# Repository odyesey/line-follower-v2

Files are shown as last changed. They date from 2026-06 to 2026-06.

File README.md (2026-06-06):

# Line follower v2

## About

As the name suggests, its the second version with custom pcb and better hardware. I use PCB as a chasis and mount all components on it. For wheels, I designed mold in CAD to make silicone tires. Tire diameter is less than wheel diameter, so it sticks better and lowers the chance of slipping off

## Features

- Detect and avoid obstacles
- PID control
- OLED Display to show values
- Buttons to tune PID values
- Buzzer to signal start
- Low voltage alarm

## How to open PCB files
- Go to EasyEDA Std
- Go to File > Open > EasyEDA
- Select easyeda.zip file in PCB folder
- Click Import

## Images

### CAD View
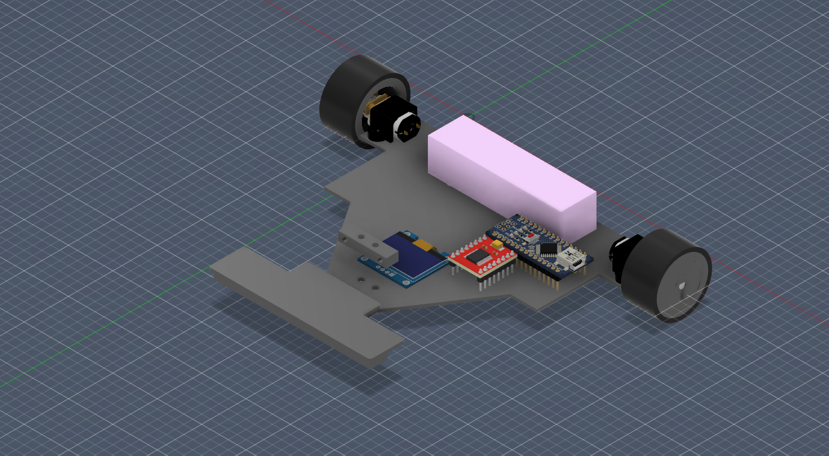
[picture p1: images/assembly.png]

**Note:** I couldn't find CAD models of some components, so I matched mount holes instead. All dimensions are correct

### 3D View
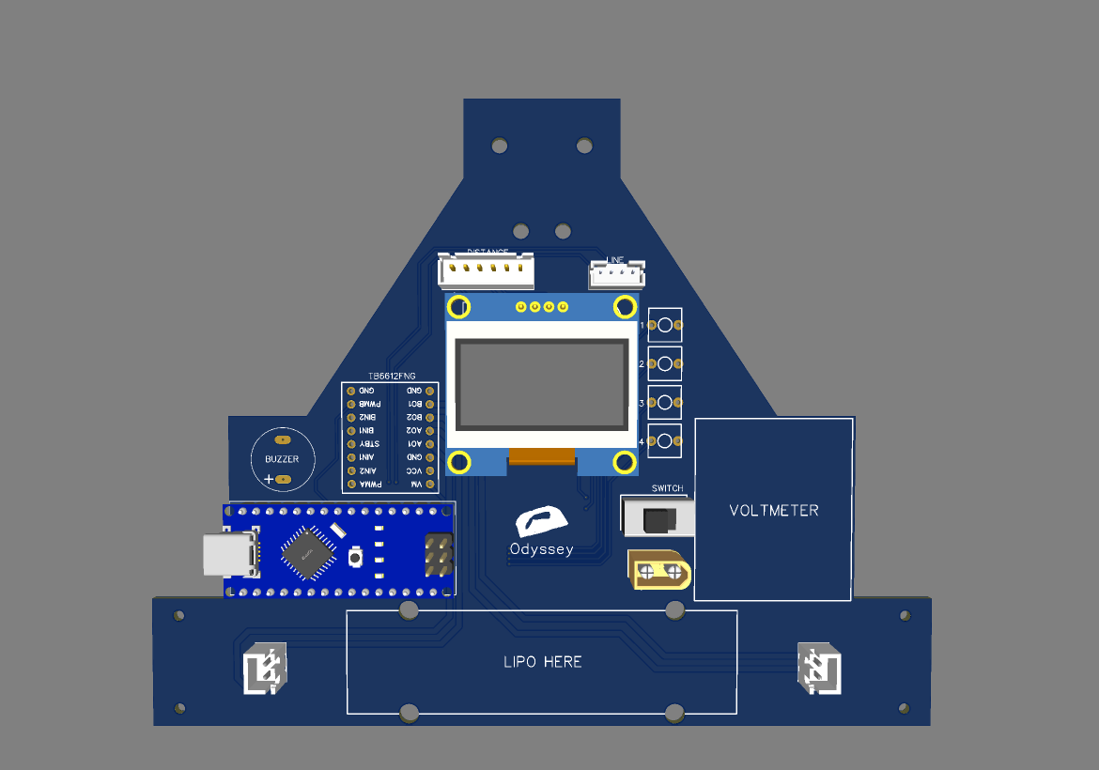
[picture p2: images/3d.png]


### 2D View
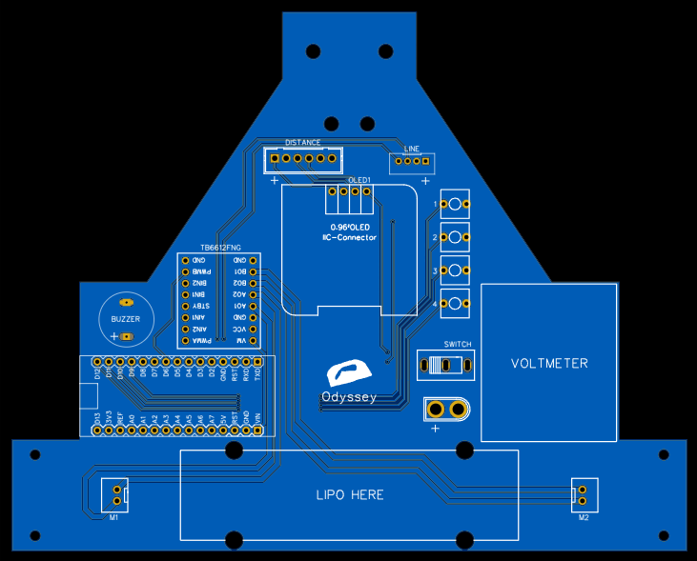
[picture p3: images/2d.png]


### Schematic
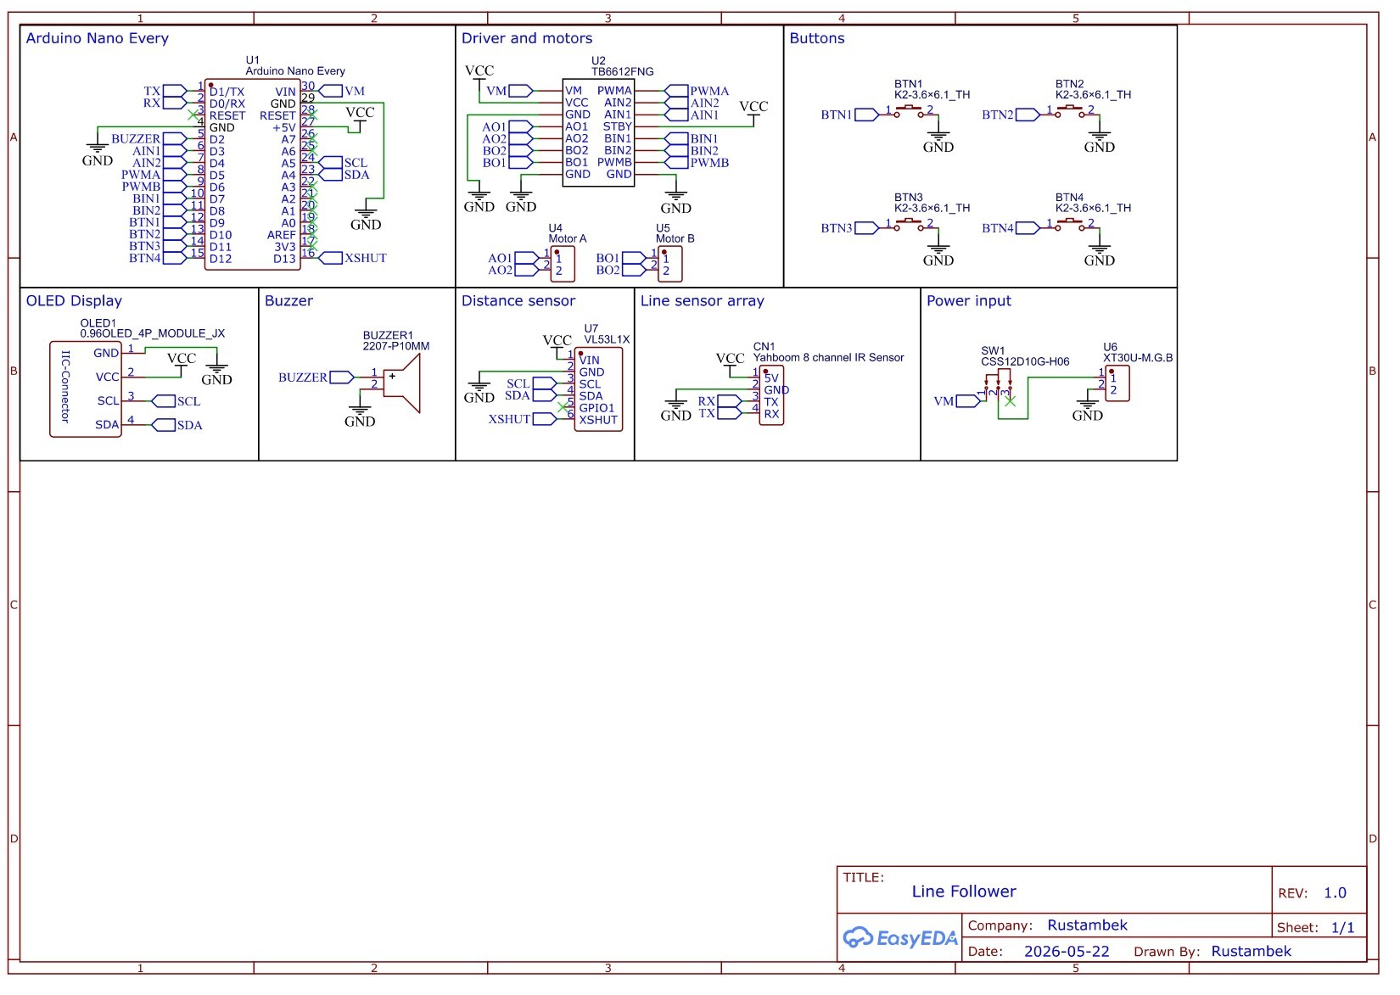
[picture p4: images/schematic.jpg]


### CAD

| Assembly | Mold |
| --- | --- |
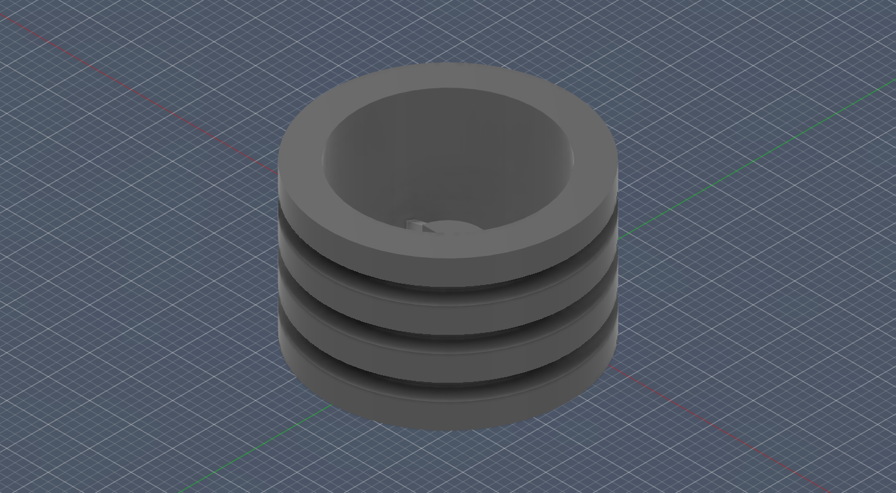
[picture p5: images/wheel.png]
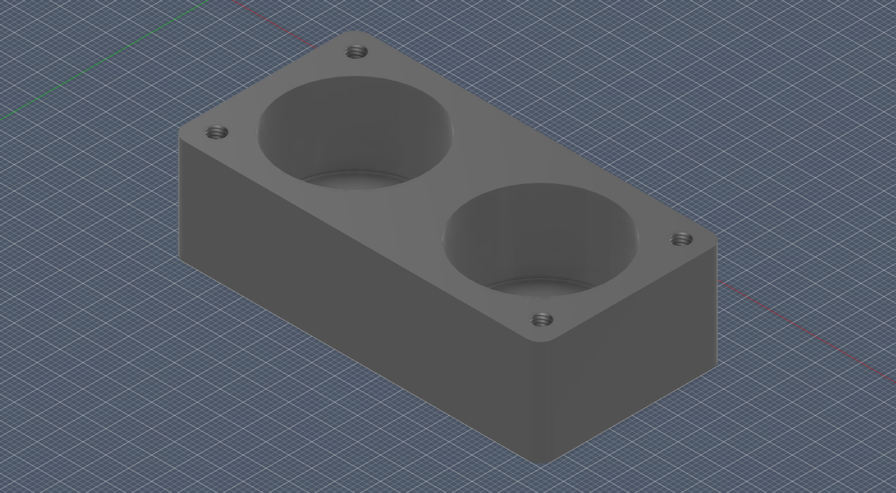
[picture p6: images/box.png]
|  box.stl |  box.stl |
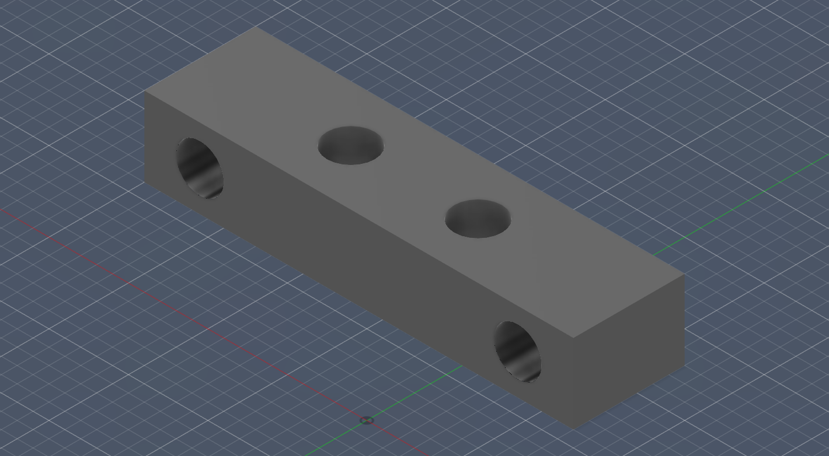
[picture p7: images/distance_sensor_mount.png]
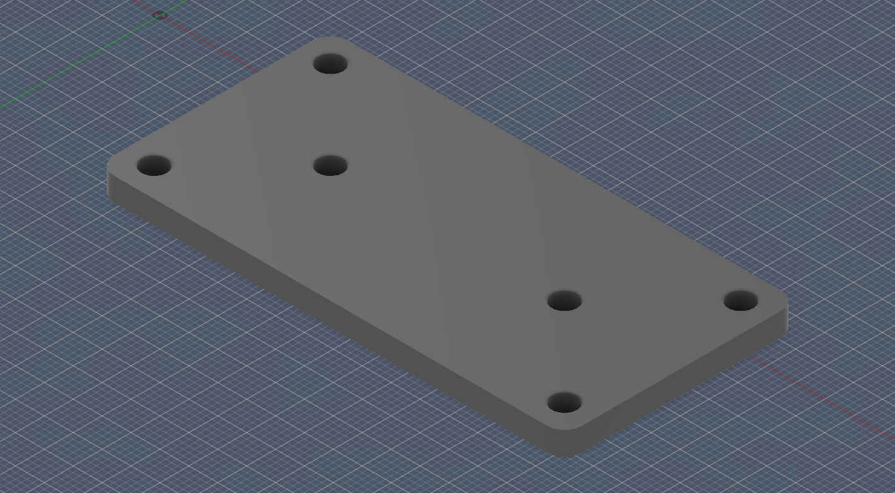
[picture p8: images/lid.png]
|  distance_sensor_mount.stl |  lid.stl|
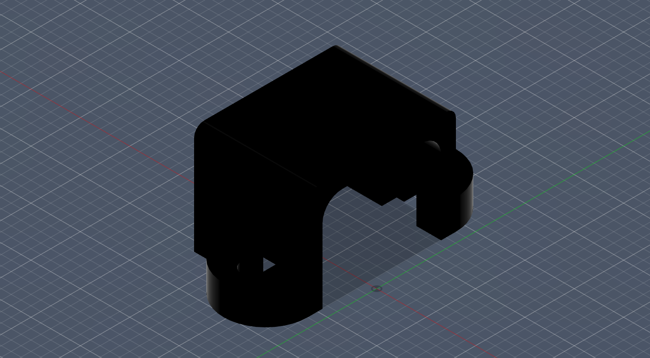
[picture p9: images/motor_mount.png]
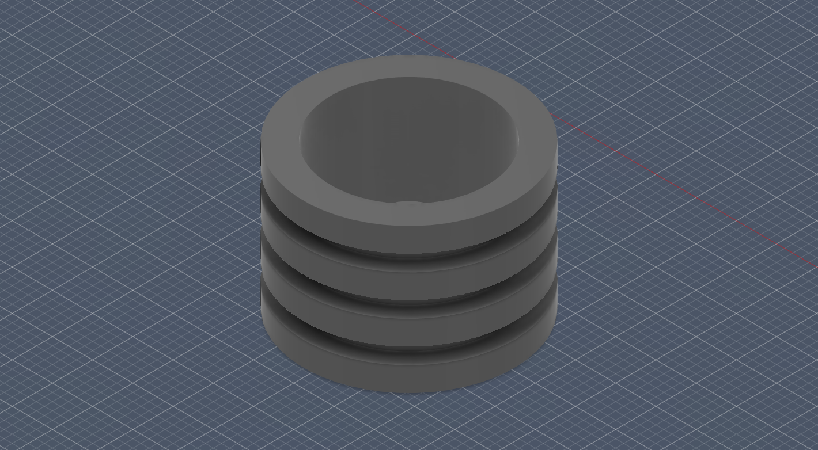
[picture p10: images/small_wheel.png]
|  motor_mount.stl |  small_wheel.stl |

**Note:** motor_mount.stl isn't mine, so uploaded copyright

## Gerbers
Gerbers file is in Fabrication folder, I chose black as a PCB color

## 3D Print (jlc3dp.com)

|File |Quantity|Material |
|---|---|---|
|box.stl |1 |JLC Black Resin|
|lid.stl |1 |JLC Black Resin|
|small_wheel.stl |2 |JLC Black Resin|
|wheel.stl |2 |PA12-HP Nylon  |
|motor_mount.stl |2 |PA12-HP Nylon  |
|distance_sensor_mount.stl|1 |PA12-HP Nylon  |

## BOM

|Name |Quantity|Total Cost (USD)|Link |
|---|---|---|---|
|N20 motor 12V 500RPM |2 |4.2 |https://ali.click/gukjd1s|
|IMAX B6 Balance charger |1 |28.48 |https://ali.click/nadmd1u|
|VL53L1X |1 |3.04 |https://ali.click/zucjd1w|
|JST PH2.0 4P connector |1 |0.78 |https://ali.click/thyid1k|
|JST XH2.54 6P wire + connector |1 |1.06 |https://ali.click/dawid1q|
|JST XH2.54 2P wire + connector |2 |0.54 |https://ali.click/jwvid1j|
|M2 screw |4 |1.76 |https://ali.click/vkvid1w|
|M2 nut |4 |0.48 |https://ali.click/bfvid1k|
|Releasable zip ties |1 |1.81 |https://ali.click/wctid1n|
|XT30U-M Connector |1 |0.88 |https://ali.click/g5tid1h|
|Switch |1 |0.98 |https://ali.click/rosid1l|
|Lipo 3s 72mm x 18mm |2 |20 |https://ali.click/qedmd18|
|Female pin header 1x15 |2 |1.26 |https://ali.click/tmyfd1y|
|Short male pin header 1x4 |1 |0.87 |https://ali.click/xeyfd1s|
|OLED Display 128x64 4P |1 |1.59 |https://ali.click/hayfd1t|
|TMB12A05 |1 |2 |https://ali.click/k2yfd11|
|Female pin header 1x8 |2 |0.73 |https://ali.click/qnxfd1k|
|2 pin button |4 |1 |https://ali.click/rzwfd1p|
|Lipo Voltmeter |1 |1.2 |https://ali.click/grcjd17|
|Arduino Nano Every |1 |16.2 |https://ali.click/9npcd1e|
|Yahboom 8 channel IR sensor (Full pack)|1 |11.95 |https://ali.click/u2svc1b|
|TB6612FNG |1 |0.86 |https://ali.click/hkdmd1x|
|M3 nut |2 |0.87 |https://ali.click/kqdmd1u|
|M4 screw length>=35mm |6 |1.68 |https://ali.click/0memd11|
|M4 nut |6 |0.73 |https://ali.click/rgemd1v|

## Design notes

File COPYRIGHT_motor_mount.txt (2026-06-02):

MODEL: https://grabcad.com/library/motor-mount-for-ga12-n20-1
AUTHOR: https://grabcad.com/tu.n.quang-6

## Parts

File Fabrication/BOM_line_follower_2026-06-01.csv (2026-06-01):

ID | Name | Designator | Footprint | Quantity | Manufacturer Part | Manufacturer | Supplier | Supplier Part | Price
1 | K2-3.6×6.1_TH | 1,2,3,4 | KEY-TH_2P | 4 | K2-1107ST-A4SW-06 |  | LCSC | C118141 | 0.074
2 | 2207-P10MM | BUZZER | BUZZER_BEEPER:BUZZER_12X9.5RM7.6 | 1 | 2207-P10MM | XHXDZ(兴华鑫) | LCSC | C49246969 | 0.153
3 | Yahboom 8 channel IR Sensor | LINE | CONN-TH_PH2.0-4P | 1 | PH2.0-4P | CAX(创都) | LCSC | C722763 | 0.014
4 | 0.96OLED_4P_MODULE_JX | OLED1 | 0.96OLED_4P | 1 | 0.96OLED_4P_MODULE_JX | null | LCSC | C9900004566
5 | CSS12D10G-H06 | SWITCH | SW-TH_3P-P4.80-HX-SS12D10G4 | 1 | CSS12D10G-H06 | JXTCONN(聚兴泰) | LCSC | C49435501 | 0.264
6 | Arduino Nano Every | U1 | COMM-TH_ARDUINO_NANO | 1 | ARDUINO_NANO | null | LCSC | C9900017879
7 | TB6612FNG | TB6612FNG | TB6612-BOARD | 1
8 | Motor A | M1 | CONN-TH_2P-P2.50-XH2.54-2P | 1 | XH-2P-2.54 | null | LCSC | C9900003929
9 | Motor B | M2 | CONN-TH_2P-P2.50-XH2.54-2P | 1 | XH-2P-2.54 | null | LCSC | C9900003929
10 | XT30U-M.G.B | U6 | CONN-TH_XT30U-M | 1 | XT30U-M.G.B | AMASS(艾迈斯) | LCSC | C19268020
11 | VL53L1X | DISTANCE | CONN-TH_B6B-XH-A-GU | 1 | B6B-XH-A-GU | JST | LCSC | C265366 | 2.362

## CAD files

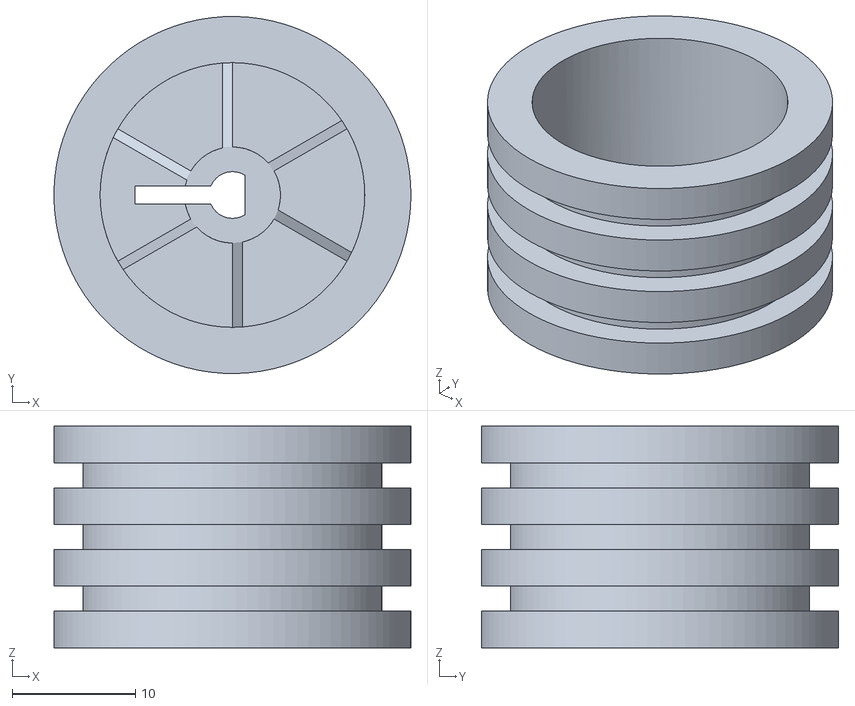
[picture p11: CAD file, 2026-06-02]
CAD/wheel.stl
29.0 x 29.0 x 18.0

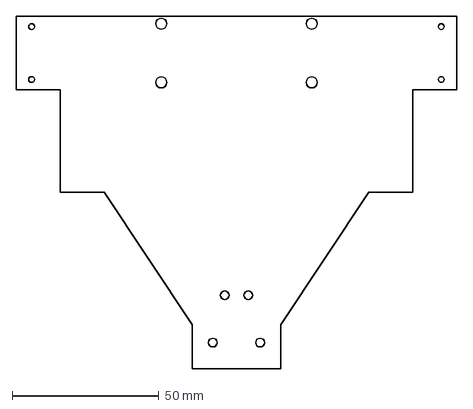
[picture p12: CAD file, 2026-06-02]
PCB/BoardOutline.dxf
150.0 x 120.0 mm

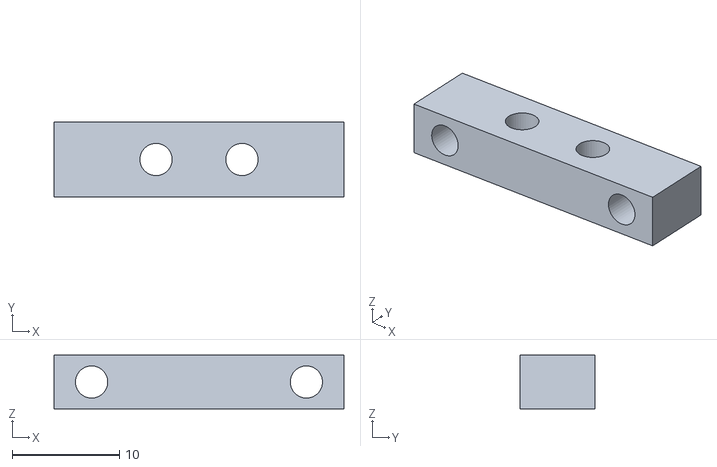
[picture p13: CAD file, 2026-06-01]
CAD/distance_sensor_mount.stl
27.0 x 7.00 x 5.00

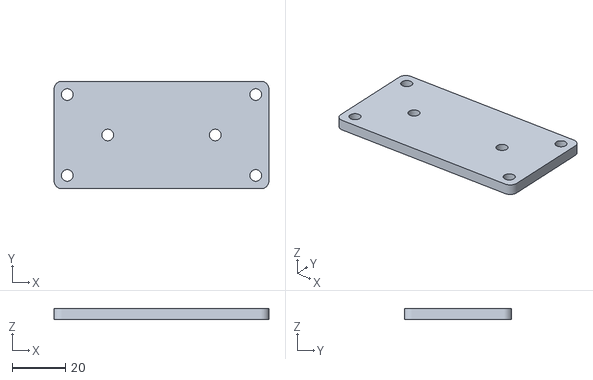
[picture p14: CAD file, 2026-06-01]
CAD/lid.stl
81.0 x 40.5 x 4.00

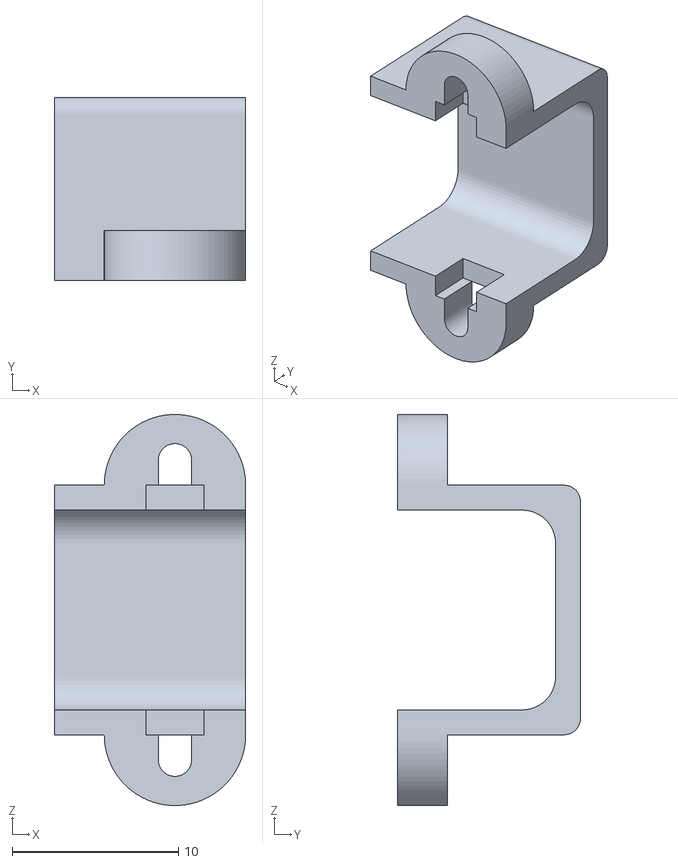
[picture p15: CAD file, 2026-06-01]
CAD/motor_mount.stl
11.5 x 11.0 x 23.5

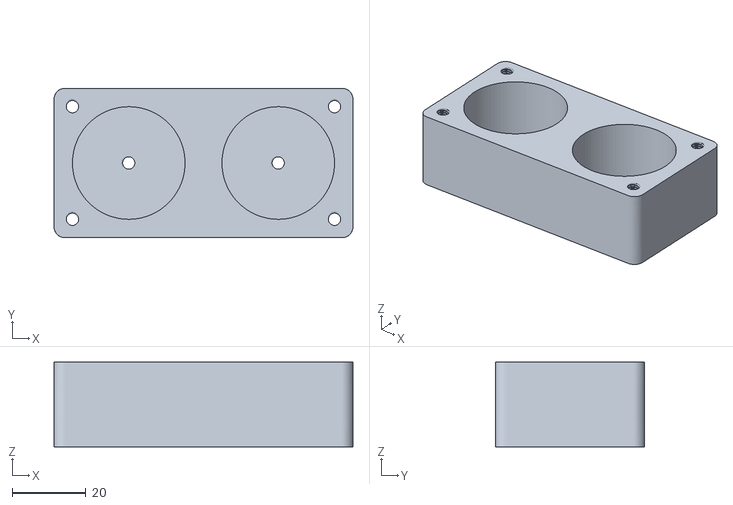
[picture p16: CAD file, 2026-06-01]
CAD/box.stl
81.0 x 40.5 x 23.0

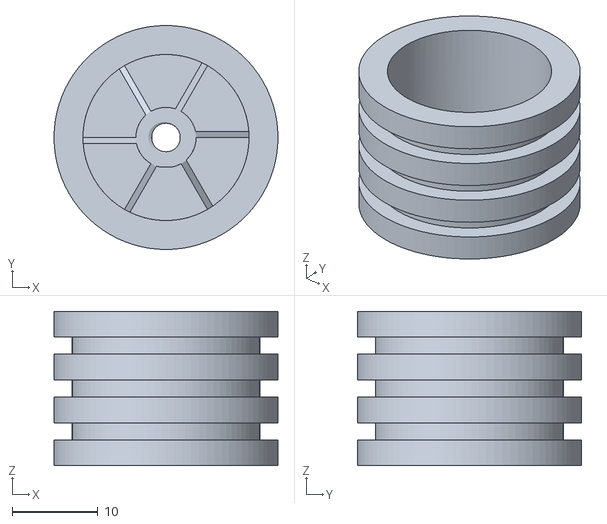
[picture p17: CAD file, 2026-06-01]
CAD/small_wheel.stl
26.1 x 26.1 x 18.0

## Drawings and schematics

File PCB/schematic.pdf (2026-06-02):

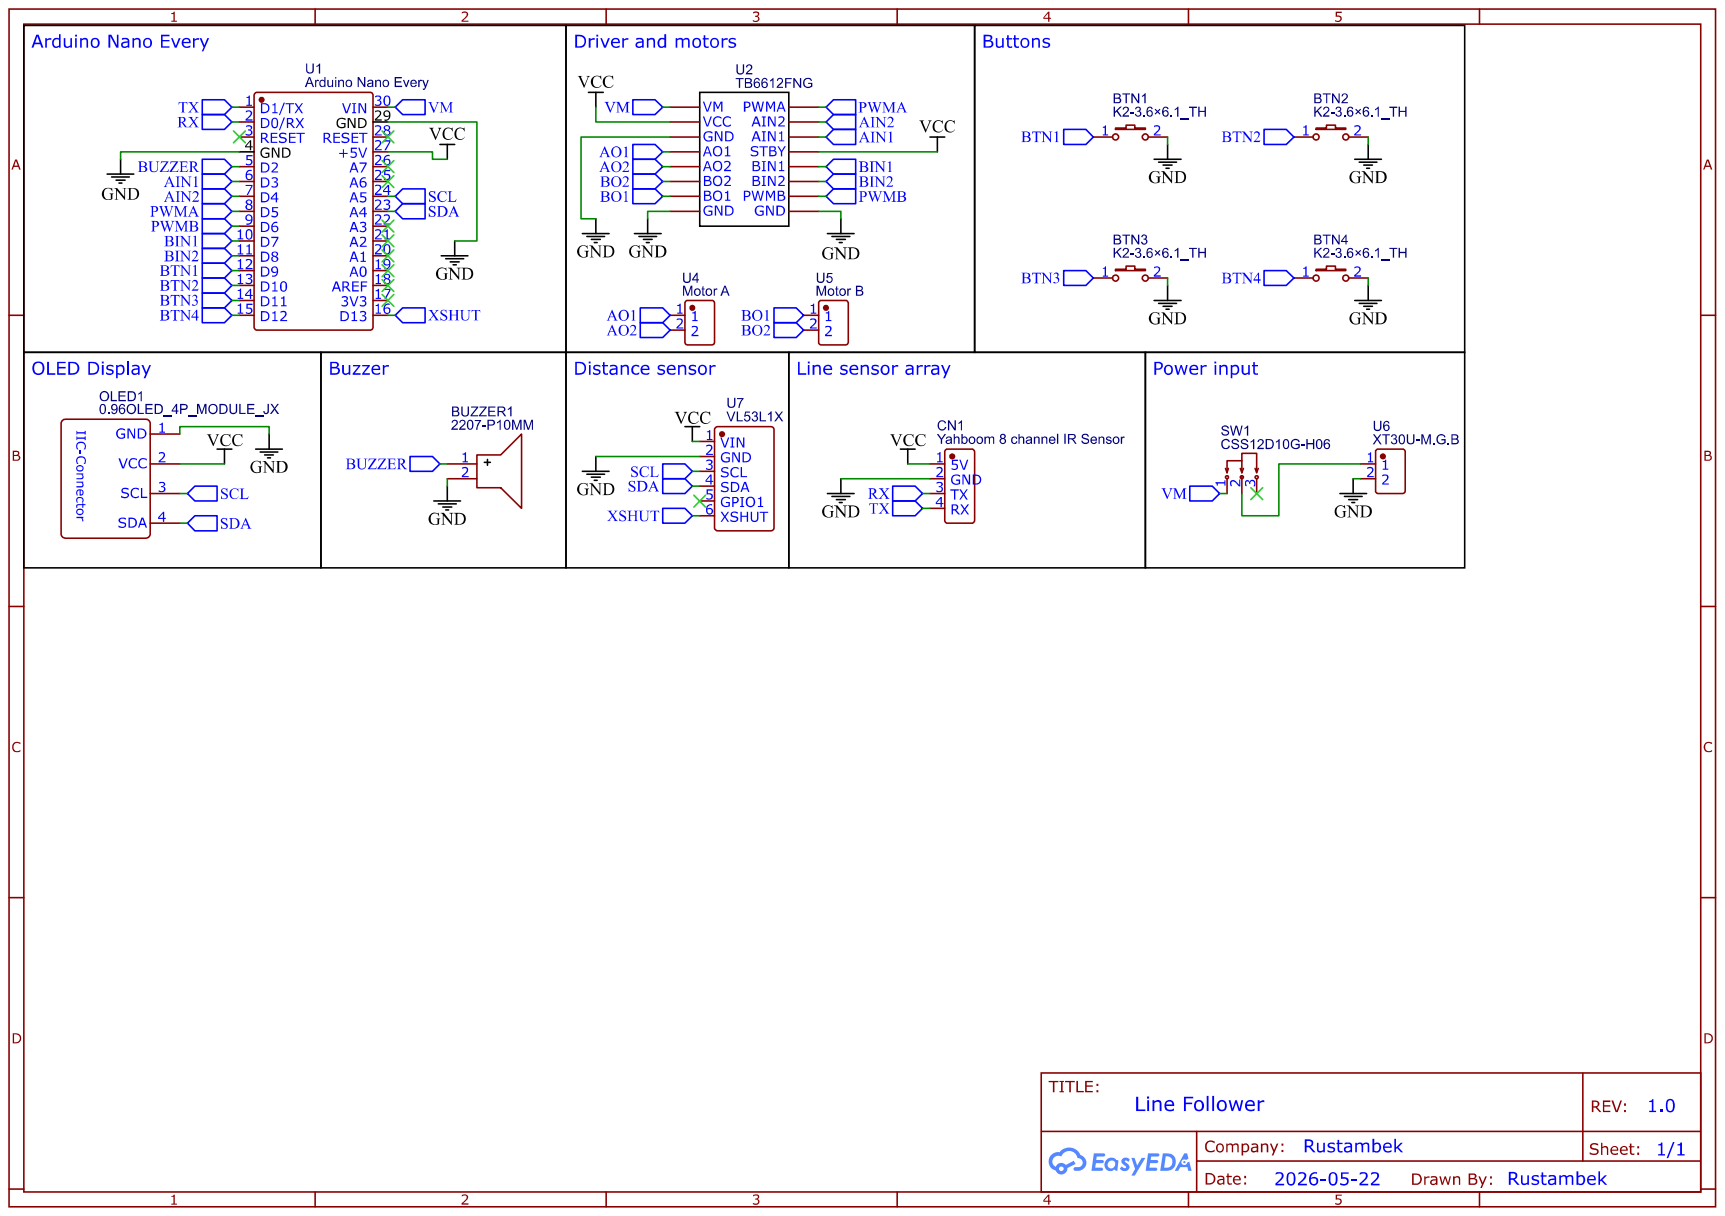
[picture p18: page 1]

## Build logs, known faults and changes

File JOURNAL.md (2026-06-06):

<!--
  This journal is auto generated by Stasis.
-->

# 6/2/2026 5 PM - Removed gyroscope, some components and updated wheel model

_Time spent: 0.25h_

schematic


Gyroscope adds extra money to the budget, and I think leaning on line sensor array is enough (8 IR sensors). I previously used LEGO EV3 gyro sensor and making exact turns was slow. If you increase speed it can overshoot. Maybe code wasn't well written. Anyway, I removed gyroscope, I don't need precise turns, robot itself will adjust its position by sensor feedback

I removed additional components of buzzer, like transistor. Because I found out, it can work directly from  digital pin

I forgot to extrude tiny face, and fixed it

Before:

After:







# 5/31/2026 8 PM - Finished pcb routing

_Time spent: 5h_



Made this in CAD to mount distance sensor. Its designed like that: you put copper columns (which comes in yahboom IR sensor array pack) on pcb and on top of that this CAD model, and mount distance sensor to the farthest holes and tighten this construction by insterting screws into copper columns (and closing them with nuts in holes without columns)



Added copper area to both layers (to GND net). I had DRC showing one unrouted GND, but I was sure all grounds are connected to each other. Even after adding copper area, this error didn't disappear. I deleted and added copper area multiple times because I messed up something (I forgot what exactly), and somehow that error disappeared



Drew a rectangle to specify a space for lipo voltmeter. It's a crucial thing because I heard if lipo battery is used at low voltage, it can burn. Voltmeter helps to monitor current voltage and beep if the battery is low, and minimum voltage to beep can be configured

The pcb's color will be black, because it looks really good. At first, I thought the blue pcb is the best option because I have colorful components (black, blue, red, green, purple). But my logo on black pcb looks better, and I think other components will blend in with this color



Made some changes for board outline: increased the space because not all components are fitting and added four holes around the battery space for zip ties (zip ties should be releaseable because I want to use 2 lipo batteries: use one while other is charging) to tighten the battery






# 5/30/2026 6 PM - Worked on pcb chasis design and placed components to check whether they fit

_Time spent: 0.75h_



Sketched this outline and drawed some circles for motor mounts and line sensor array. I should add more circles for distance sensor. Removed other lines because when importing it as a dxf, EasyEDA uses these lines as a border and cuts them into multiple PCBs. Later I found out, I could just simply remove these lines in pcb editor man



In importing dxf, you can check option that uses circles as a mount hole in EasyEDA. So convenient!

After importing board outline, it looked small, and started to worry that all components may not fit inside. But after placing tightly, they all fit inside



This isn't the final version. I should add some mount holes for a distance sensor





# 5/29/2026 1 PM - Completed the schematic

_Time spent: 1h_



Finally, finished it. That was a long run not gonna lie

I added switch and four buttons (they can be used to tune PID values without uploading a new code and start a robot with one click because line sensor array needs to be initalized first and this doesn't happen instanly, so it doesn't makes sense to run robot right after turning on)

XSHUT pin of distance sensor is now connected to digital pin



For the buzzer part, AI suggested me this diagram, and I tested it in tinkercad. I thought boom (on image) indicates arduino started working. When I pulled up another arduino with led, it worked without booms. I started to worry, maybe in real life this can burn transistor. But the reason was piezo drawing too much current. The buzzer I found draws less than 30mA of current, which is quite low to cause heating, so we are good




# 5/29/2026 9 AM - Almost finished schematic

_Time spent: 2h_



I did a lot of research not only with AI, but searched for sources on the internet. Looked for wirings and clarified things like sensor operating voltage. I'm using Yahboom's IR sensor array, so I contacted them via email to make sure I can connect to sensor with pcb

In schematic, I didn't include voltmeter for lipo battery because there is no need to do that. It automatically makes a sound when voltage is low, and minimum voltage can be configured, you just connect it to lipo. The only thing is to allocate space in pcb

This schematic at this point, is complete, except XSHUT pin in distance sensor

There a few things left: switch for turning on/off, buzzer to indicate robot started following line, and a few buttons just in case. Maybe I'll add more components



# 5/27/2026 3 PM - Uploaded models for JLC3DP

_Time spent: 0.75h_



At first, I just exported models apart and uploaded to website. I thought everthing is going to be fine, but I encountered printing risk on box.stl (in screenshot), used AI to figure out the problem, tried extruding bottom part and that worked! Used AI again, to determine which 3d printing technology to use and chose MJF (Nylon)

Honestly, I didn't expect printing price would be that much



# 5/27/2026 12 PM - Designed mold for making silicone tires

_Time spent: 0.75h_



I scaled x and y axis of the wheel from 1.0 to 0.9, so tire width remains unchanged. This makes silicone's diameter smaller than actual wheel's diamteter. That means silicone tire will stick stronger to wheels

I carved holes and made thread from them for M4 bolts, and I set tires outer thickness to 2.2mm

Used this tutorial: https://www.youtube.com/watch?v=wSwuph2TElI



# 5/25/2026 4 PM - Finished the wheel

_Time spent: 1.333333333333333h_





Changed the smooth sank middle to 3-channel design. This reduces the chances of slipping of. Also I changed support beams to triangular shape, and made wheel 2 times wider

I increased the "tip" of the wheel (where motor shaft goes) to 1mm, so widened wheel won't cover the motor that much




# 5/24/2026 4 PM - Designed wheel

_Time spent: 1h_





I designed wheels for n20 motors. Used [this](https://grabcad.com/library/wheel-43mm-for-ga12-n20-1) cad model as a reference to match the dimensions

It was hard to make "inward fillet" (smooth face of the wheel), took me a while to accomplish. I'm going to apply silicone, so it has to stick tight. I saw [someone's video on youtube](https://youtu.be/vx1lCHlVZqE?t=473), and he used different approach for that. I think his approach better than mine, and I'm planning to use his. Also, I should make support beams triangular




# 5/24/2026 10 AM - Prototyped pcb chasis and imported symbols

_Time spent: 1.25h_



Since I'm new to hardware, I consulted with AI a lot through the process. It suggested me to design whole chasis in pcb. That was a great idea, and I started prototyping in cad. Some components don't have 3d design, and I designed them on my own, not perfect but good for prototyping

Instead of jumper wires, I used JST connectors. They are very convenient, and you can't physically reverse wires. Once connected, they won't go out easily like jumper wires


In some sensors, I used pin headers, instead of their symbol, and named pins according to actual sensor pin names




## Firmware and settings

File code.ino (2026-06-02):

/**************************************************************************
 This is an example for our Monochrome OLEDs based on SSD1306 drivers

 Pick one up today in the adafruit shop!
 ------> http://www.adafruit.com/category/63_98

 This example is for a 128x64 pixel display using I2C to communicate
 3 pins are required to interface (two I2C and one reset).

 Adafruit invests time and resources providing this open
 source code, please support Adafruit and open-source
 hardware by purchasing products from Adafruit!

 Written by Limor Fried/Ladyada for Adafruit Industries,
 with contributions from the open source community.
 BSD license, check license.txt for more information
 All text above, and the splash screen below must be
 included in any redistribution.
 **************************************************************************/

#include <SPI.h>
#include <Wire.h>
#include <Adafruit_GFX.h>
#include <Adafruit_SSD1306.h>

#define SCREEN_WIDTH 128 // OLED display width, in pixels
#define SCREEN_HEIGHT 64 // OLED display height, in pixels

// Declaration for an SSD1306 display connected to I2C (SDA, SCL pins)
// The pins for I2C are defined by the Wire-library. 
// On an arduino UNO:       A4(SDA), A5(SCL)
// On an arduino MEGA 2560: 20(SDA), 21(SCL)
// On an arduino LEONARDO:   2(SDA),  3(SCL), ...
#define OLED_RESET     -1 // Reset pin # (or -1 if sharing Arduino reset pin)
#define SCREEN_ADDRESS 0x3D ///< See datasheet for Address; 0x3D for 128x64, 0x3C for 128x32
Adafruit_SSD1306 display(SCREEN_WIDTH, SCREEN_HEIGHT, &Wire, OLED_RESET);

#define NUMFLAKES     10 // Number of snowflakes in the animation example

#define LOGO_HEIGHT   16
#define LOGO_WIDTH    16
static const unsigned char PROGMEM logo_bmp[] =
{ 0b00000000, 0b11000000,
  0b00000001, 0b11000000,
  0b00000001, 0b11000000,
  0b00000011, 0b11100000,
  0b11110011, 0b11100000,
  0b11111110, 0b11111000,
  0b01111110, 0b11111111,
  0b00110011, 0b10011111,
  0b00011111, 0b11111100,
  0b00001101, 0b01110000,
  0b00011011, 0b10100000,
  0b00111111, 0b11100000,
  0b00111111, 0b11110000,
  0b01111100, 0b11110000,
  0b01110000, 0b01110000,
  0b00000000, 0b00110000 };

void setup() {
  Serial.begin(9600);

  // Wait for display
  delay(500);

  // SSD1306_SWITCHCAPVCC = generate display voltage from 3.3V internally
  if(!display.begin(SSD1306_SWITCHCAPVCC, SCREEN_ADDRESS)) {
    Serial.println(F("SSD1306 allocation failed"));
    for(;;); // Don't proceed, loop forever
  }

  // Show initial display buffer contents on the screen --
  // the library initializes this with an Adafruit splash screen.
  display.display();
  delay(2000); // Pause for 2 seconds

  // Clear the buffer
  display.clearDisplay();

  // Draw a single pixel in white
  display.drawPixel(10, 10, SSD1306_WHITE);

  // Show the display buffer on the screen. You MUST call display() after
  // drawing commands to make them visible on screen!
  display.display();
  delay(2000);
  // display.display() is NOT necessary after every single drawing command,
  // unless that's what you want...rather, you can batch up a bunch of
  // drawing operations and then update the screen all at once by calling
  // display.display(). These examples demonstrate both approaches...

  testdrawline();      // Draw many lines

  testdrawrect();      // Draw rectangles (outlines)

  testfillrect();      // Draw rectangles (filled)

  testdrawcircle();    // Draw circles (outlines)

  testfillcircle();    // Draw circles (filled)

  testdrawroundrect(); // Draw rounded rectangles (outlines)

  testfillroundrect(); // Draw rounded rectangles (filled)

  testdrawtriangle();  // Draw triangles (outlines)

  testfilltriangle();  // Draw triangles (filled)

  testdrawchar();      // Draw characters of the default font

  testdrawstyles();    // Draw 'stylized' characters

  testscrolltext();    // Draw scrolling text

  testdrawbitmap();    // Draw a small bitmap image

  // Invert and restore display, pausing in-between
  display.invertDisplay(true);
  delay(1000);
  display.invertDisplay(false);
  delay(1000);

  testanimate(logo_bmp, LOGO_WIDTH, LOGO_HEIGHT); // Animate bitmaps
}

void loop() {
}

void testdrawline() {
  int16_t i;

  display.clearDisplay(); // Clear display buffer

  for(i=0; i<display.width(); i+=4) {
    display.drawLine(0, 0, i, display.height()-1, SSD1306_WHITE);
    display.display(); // Update screen with each newly-drawn line
    delay(1);
  }
  for(i=0; i<display.height(); i+=4) {
    display.drawLine(0, 0, display.width()-1, i, SSD1306_WHITE);
    display.display();
    delay(1);
  }
  delay(250);

  display.clearDisplay();

  for(i=0; i<display.width(); i+=4) {
    display.drawLine(0, display.height()-1, i, 0, SSD1306_WHITE);
    display.display();
    delay(1);
  }
  for(i=display.height()-1; i>=0; i-=4) {
    display.drawLine(0, display.height()-1, display.width()-1, i, SSD1306_WHITE);
    display.display();
    delay(1);
  }
  delay(250);

  display.clearDisplay();

  for(i=display.width()-1; i>=0; i-=4) {
    display.drawLine(display.width()-1, display.height()-1, i, 0, SSD1306_WHITE);
    display.display();
    delay(1);
  }
  for(i=display.height()-1; i>=0; i-=4) {
    display.drawLine(display.width()-1, display.height()-1, 0, i, SSD1306_WHITE);
    display.display();
    delay(1);
  }
  delay(250);

  display.clearDisplay();

  for(i=0; i<display.height(); i+=4) {
    display.drawLine(display.width()-1, 0, 0, i, SSD1306_WHITE);
    display.display();
    delay(1);
  }
  for(i=0; i<display.width(); i+=4) {
    display.drawLine(display.width()-1, 0, i, display.height()-1, SSD1306_WHITE);
    display.display();
    delay(1);
  }

  delay(2000); // Pause for 2 seconds
}

void testdrawrect(void) {
  display.clearDisplay();

  for(int16_t i=0; i<display.height()/2; i+=2) {
    display.drawRect(i, i, display.width()-2*i, display.height()-2*i, SSD1306_WHITE);
    display.display(); // Update screen with each newly-drawn rectangle
    delay(1);
  }

  delay(2000);
}

void testfillrect(void) {
  display.clearDisplay();

  for(int16_t i=0; i<display.height()/2; i+=3) {
    // The INVERSE color is used so rectangles alternate white/black
    display.fillRect(i, i, display.width()-i*2, display.height()-i*2, SSD1306_INVERSE);
    display.display(); // Update screen with each newly-drawn rectangle
    delay(1);
  }

  delay(2000);
}

void testdrawcircle(void) {
  display.clearDisplay();

  for(int16_t i=0; i<max(display.width(),display.height())/2; i+=2) {
    display.drawCircle(display.width()/2, display.height()/2, i, SSD1306_WHITE);
    display.display();
    delay(1);
  }

  delay(2000);
}

void testfillcircle(void) {
  display.clearDisplay();

  for(int16_t i=max(display.width(),display.height())/2; i>0; i-=3) {
    // The INVERSE color is used so circles alternate white/black
    display.fillCircle(display.width() / 2, display.height() / 2, i, SSD1306_INVERSE);
    display.display(); // Update screen with each newly-drawn circle
    delay(1);
  }

  delay(2000);
}

void testdrawroundrect(void) {
  display.clearDisplay();

  for(int16_t i=0; i<display.height()/2-2; i+=2) {
    display.drawRoundRect(i, i, display.width()-2*i, display.height()-2*i,
      display.height()/4, SSD1306_WHITE);
    display.display();
    delay(1);
  }

  delay(2000);
}

void testfillroundrect(void) {
  display.clearDisplay();

  for(int16_t i=0; i<display.height()/2-2; i+=2) {
    // The INVERSE color is used so round-rects alternate white/black
    display.fillRoundRect(i, i, display.width()-2*i, display.height()-2*i,
      display.height()/4, SSD1306_INVERSE);
    display.display();
    delay(1);
  }

  delay(2000);
}

void testdrawtriangle(void) {
  display.clearDisplay();

  for(int16_t i=0; i<max(display.width(),display.height())/2; i+=5) {
    display.drawTriangle(
      display.width()/2  , display.height()/2-i,
      display.width()/2-i, display.height()/2+i,
      display.width()/2+i, display.height()/2+i, SSD1306_WHITE);
    display.display();
    delay(1);
  }

  delay(2000);
}

void testfilltriangle(void) {
  display.clearDisplay();

  for(int16_t i=max(display.width(),display.height())/2; i>0; i-=5) {
    // The INVERSE color is used so triangles alternate white/black
    display.fillTriangle(
      display.width()/2  , display.height()/2-i,
      display.width()/2-i, display.height()/2+i,
      display.width()/2+i, display.height()/2+i, SSD1306_INVERSE);
    display.display();
    delay(1);
  }

  delay(2000);
}

void testdrawchar(void) {
  display.clearDisplay();

  display.setTextSize(1);      // Normal 1:1 pixel scale
  display.setTextColor(SSD1306_WHITE); // Draw white text
  display.setCursor(0, 0);     // Start at top-left corner
  display.cp437(true);         // Use full 256 char 'Code Page 437' font

  // Not all the characters will fit on the display. This is normal.
  // Library will draw what it can and the rest will be clipped.
  for(int16_t i=0; i<256; i++) {
    if(i == '\n') display.write(' ');
    else          display.write(i);
  }

  display.display();
  delay(2000);
}

void testdrawstyles(void) {
  display.clearDisplay();

  display.setTextSize(1);             // Normal 1:1 pixel scale
  display.setTextColor(SSD1306_WHITE);        // Draw white text
  display.setCursor(0,0);             // Start at top-left corner
  display.println(F("Hello, world!"));

  display.setTextColor(SSD1306_BLACK, SSD1306_WHITE); // Draw 'inverse' text
  display.println(3.141592);

  display.setTextSize(2);             // Draw 2X-scale text
  display.setTextColor(SSD1306_WHITE);
  display.print(F("0x")); display.println(0xDEADBEEF, HEX);

  display.display();
  delay(2000);
}

void testscrolltext(void) {
  display.clearDisplay();

  display.setTextSize(2); // Draw 2X-scale text
  display.setTextColor(SSD1306_WHITE);
  display.setCursor(10, 0);
  display.println(F("scroll"));
  display.display();      // Show initial text
  delay(100);

  // Scroll in various directions, pausing in-between:
  display.startscrollright(0x00, 0x0F);
  delay(2000);
  display.stopscroll();
  delay(1000);
  display.startscrollleft(0x00, 0x0F);
  delay(2000);
  display.stopscroll();
  delay(1000);
  display.startscrolldiagright(0x00, 0x07);
  delay(2000);
  display.startscrolldiagleft(0x00, 0x07);
  delay(2000);
  display.stopscroll();
  delay(1000);
}

void testdrawbitmap(void) {
  display.clearDisplay();

  display.drawBitmap(
    (display.width()  - LOGO_WIDTH ) / 2,
    (display.height() - LOGO_HEIGHT) / 2,
    logo_bmp, LOGO_WIDTH, LOGO_HEIGHT, 1);
  display.display();
  delay(1000);
}

#define XPOS   0 // Indexes into the 'icons' array in function below
#define YPOS   1
#define DELTAY 2

void testanimate(const uint8_t *bitmap, uint8_t w, uint8_t h) {
  int8_t f, icons[NUMFLAKES][3];

  // Initialize 'snowflake' positions
  for(f=0; f< NUMFLAKES; f++) {
    icons[f][XPOS]   = random(1 - LOGO_WIDTH, display.width());
    icons[f][YPOS]   = -LOGO_HEIGHT;
    icons[f][DELTAY] = random(1, 6);
    Serial.print(F("x: "));
    Serial.print(icons[f][XPOS], DEC);
    Serial.print(F(" y: "));
    Serial.print(icons[f][YPOS], DEC);
    Serial.print(F(" dy: "));
    Serial.println(icons[f][DELTAY], DEC);
  }

  for(;;) { // Loop forever...
    display.clearDisplay(); // Clear the display buffer

    // Draw each snowflake:
    for(f=0; f< NUMFLAKES; f++) {
      display.drawBitmap(icons[f][XPOS], icons[f][YPOS], bitmap, w, h, SSD1306_WHITE);
    }

    display.display(); // Show the display buffer on the screen
    delay(200);        // Pause for 1/10 second

    // Then update coordinates of each flake...
    for(f=0; f< NUMFLAKES; f++) {
      icons[f][YPOS] += icons[f][DELTAY];
      // If snowflake is off the bottom of the screen...
      if (icons[f][YPOS] >= display.height()) {
        // Reinitialize to a random position, just off the top
        icons[f][XPOS]   = random(1 - LOGO_WIDTH, display.width());
        icons[f][YPOS]   = -LOGO_HEIGHT;
        icons[f][DELTAY] = random(1, 6);
      }
    }
  }
}

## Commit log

2026-06-02 Upload pcb archive
    [BoardOutline.dxf]
2026-10-12 Upload Fusion file of assembly
2026-10-12 Add total to README BOM and extracted EasyEda Std zip file
